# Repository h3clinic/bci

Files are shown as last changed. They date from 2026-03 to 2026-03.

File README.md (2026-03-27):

# BioGENEius Neural Signal Analysis Pipeline

## Model Details

| Field | Value |
|---|---|
| **Name** | BioGENEius Computational Pipeline v1 |
| **Version** | 1.0.0 |
| **Architecture** | Two-stage: Classical (CUSUM/RF) + Deep (NeuralQANet) |
| **Parameters** | 76,045 (Deep model) |
| **Framework** | PyTorch (CPU-only, no GPU required) |
| **License** | Research use only |

## Framing

> Artifact-resilient detection of suppression-like electrophysiological
> perturbation signatures under a low-cost phantom protocol.

**Key constraint:** We never claim neurons until we have biology.

## Intended Use

Detection and classification of electrophysiological perturbation signatures
in multichannel time-series data acquired from a low-cost phantom system.
Designed for competition demonstration and research prototyping.

### Primary Use Cases
- Detecting onset of suppression-like perturbations in phantom recordings
- Classifying perturbation cause (9 synthetic proxy classes)
- Quantifying detection latency and classification confidence
- Generating reproducible evaluation reports

### Out of Scope
- Clinical diagnosis or treatment decisions
- Real-time closed-loop neural interfaces
- Claims about biological neurotoxicity from proxy labels

## Pipeline Architecture

```
Acquire (frames → ADC → µV)
  ↓
QC / Artifact Segmentation (ML mask + quality score)
  ↓
Detect Change (CUSUM or z-score baseline comparison)
  ↓
Classify Cause (RF vs Deep model, 9-class + binary)
  ↓
Report (figures + latency + CI + confidence + "unknown" option)
```

### Stage 1 — Classical Detection
- **CUSUM** change-point detection on channel-averaged RMS
- **Z-score** alternative with sliding baseline window
- Outputs: detected (bool), detection latency (seconds), CUSUM statistic

### Stage 2 — Classical Classification
- **Random Forest** on 20 handcrafted features (RMS ratio, spectral entropy, band powers, etc.)
- Binary (perturbation vs baseline) + 9-class cause classification
- Wilson confidence intervals on all accuracy metrics

### Stage 3 — Deep Classification (NeuralQANet)
- 1D CNN backbone → attention pooling → 3 heads:
  - Artifact mask (binary per-sample)
  - Cause classification (9-class)
  - Severity regression (continuous 0–1)
- Self-supervised pretraining: masked reconstruction + NT-Xent contrastive loss
- 7 domain-randomization augmentations: 60Hz injection, channel dropout, gain jitter, coupling, drift, clipping, time mask
- Temperature-calibrated output probabilities

## Proxy Labels — What We Claim and What We Don't

All perturbation classes are **proxy signatures†**, not validated biological effects:

| Class | Proxy Signature | What It Actually Is |
|---|---|---|
| Spike Suppression† | Reduced spike amplitude/rate | Synthetic amplitude modulation |
| Burst Collapse† | Loss of burst patterns | Synthetic burst removal |
| Spectral Shift† | Changed power spectrum | Synthetic PSD warping |
| Mixed Suppression† | Combined signatures | Multiple synthetic effects |
| Amplitude Modulation† | Gain changes | Synthetic scaling |
| Frequency Drift† | Center frequency shift | Synthetic frequency modulation |
| Baseline Drift† | DC offset wander | Synthetic drift injection |
| Coupling Change† | Inter-channel correlation shift | Synthetic coupling matrix |
| Artifact Injection† | Non-physiological transient | Synthetic artifact waveforms |

**†** = proxy label. Biological validation requires phantom recordings
with known perturbation agents under controlled conditions.

## Training Data

- **Source**: `analysis/perturbation_library.py` — deterministic synthetic generators
- **Classes**: 9 perturbation types + baseline
- **Severities**: 3 levels (0.3, 0.6, 0.9)
- **Channels**: 16 (configurable)
- **Sample rate**: 20 kHz (configurable)
- **Augmentations**: 7 domain-randomization transforms

**No real biological data was used for training or evaluation.**

## Evaluation Protocol

| Figure | What It Tests |
|---|---|
| Fig 1 | Onset detection latency + false positive rate |
| Fig 2 | Cause classification confusion matrix + ROC |
| Fig 3 | Robustness under noise and artifact stress |
| Fig 4 | Ablation — why two-stage matters |
| Fig 5 | 3-way comparison: Classical vs RF vs Deep |
| Fig 6 | Stress grid: SNR × severity (where Deep beats Classical) |
| Fig 7 | Domain shift: train A / test B generalization |

### ML Earns Its Keep
- **Random noise floor**: ML does NOT beat physics. PCB shielding + analog design does.
- **Structured artifacts**: ML DOES help with 60Hz, coupling, drift, and other patterned contamination.
- Deep model must beat RF baseline to be included; RF must beat CUSUM to be included.

## Known Limitations

1. **Synthetic only** — All training/evaluation on synthetic perturbation library. No real data yet.
2. **Domain shift** — Performance may degrade when real phantom data differs from synthetic assumptions.
3. **Small model** — 76K params is deliberately small for CPU inference; may under-fit complex patterns.
4. **Temperature calibration** — Calibrated on synthetic validation set; re-calibrate on real data.
5. **Proxy labels** — No biological ground truth. Labels describe electrical signatures, not mechanisms.
6. **Single phantom protocol** — Validated only against BioGENEius Phantom Protocol v2.

## "Unknown" Behavior

When the model encounters data that doesn't match any trained class:
- Top-class probability drops below 0.3
- System flags as "low-confidence" in predictions.csv
- **Intended behavior: don't make a call when you don't know**

## Reproducibility

```bash
# One command. Generates everything.
python analysis/run_pipeline.py --source synthetic --seed 42

# Outputs to out/run_YYYYMMDD_HHMMSS/:
#   fig1–fig7 (PNG), predictions.csv, metrics.json, model_card.md
```

All random state is seeded. Same seed → same results.

## Ethical Considerations

- This system processes synthetic electrical signals, not human data
- No patient data, no clinical decisions, no diagnostic claims
- Proxy labels are clearly marked to prevent over-interpretation
- "Unknown" class prevents forced classification of novel patterns
- All code and evaluation are fully reproducible and auditable

## Citation

If referencing this work, please cite the BioGENEius competition entry
and note that all results are from synthetic simulation studies.

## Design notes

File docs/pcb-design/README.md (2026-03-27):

# Neural AFE Platform - PCB Design Directions

This directory contains the complete design direction set for a 128-channel neural analog front-end (AFE) platform intended for **in-vitro instrumentation**.

## Document Structure

| Document | Purpose |
|---|---|
| `00-board-architecture.md` | Board type decisions and system partitioning |
| `01-requirements-template.md` | Requirements freeze checklist (fill before design) |
| `02-block-architecture.md` | Schematic block definitions and interfaces |
| `03-schematic-capture.md` | Hierarchical schematic organization and workflow |
| `04-layout-rules.md` | Critical layout constraints for neural-level signals |
| `05-bringup-plan.md` | Systematic board bring-up and validation |
| `06-configuration-worksheet.md` | Your specific parameters (fs, egress, etc.) |

## Design Philosophy

1. **Noise is the enemy** — every decision trades off noise
2. **Testability is non-negotiable** — no injection path = weeks of guessing
3. **Separate analog from digital** — physically, electrically, thermally
4. **Lock requirements before drawing** — designing blind wastes boards

## Quick Start

1. Fill out `06-configuration-worksheet.md` with your specific parameters
2. Review `00-board-architecture.md` to confirm board partitioning
3. Complete `01-requirements-template.md` and freeze it
4. Follow schematic and layout documents in order

## Status

- [ ] Configuration worksheet completed
- [ ] Requirements frozen
- [ ] Schematic capture complete
- [ ] Layout complete
- [ ] Fabrication
- [ ] Bring-up complete

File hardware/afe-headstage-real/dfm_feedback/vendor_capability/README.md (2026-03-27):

# Vendor Capability Evidence

Store evidence that your chosen PCB vendor can perform IPC-4761 Type VII
VIPPO (epoxy plug + copper cap) for:

- Drill: 0.200 mm
- Pad:   0.400 mm
- Board: 4-layer, 1.6 mm, FR4

## Required evidence (at least one):

- Email confirmation from vendor CAM engineer (PDF export)
- Screenshot of vendor capability page showing Type VII
- Order line item or quote showing VIPPO selected
- Vendor datasheet for via fill process

## Naming convention:

    <vendor>_<YYYYMMDD>_vippo_capability.<ext>

Example:
    jlcpcb_20260301_vippo_capability.pdf
    pcbway_20260315_vippo_capability.png

## Required keywords in evidence:

At least one file must contain references to:
- Type VII (or IPC-4761 Type VII)
- Epoxy plug (or via fill)
- Copper cap (or cap plating)
- Via-in-pad

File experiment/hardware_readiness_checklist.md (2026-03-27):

# Hardware Readiness Checklist v1.0

**Board:** AFE Headstage v1 (afe-headstage-v1)  
**Order:** JLCPCB 12006563A-Y3  
**Date:** 2026-03-02  
**Runtime contract:** `experiment/device_runtime_contract_v1.md`  
**Phantom protocol:** `experiment/phantom_protocol_v2.md`

---

## Pre-Requisites

- [ ] Board(s) received and inspected for shipping damage
- [ ] Stencil received (if ordered)
- [ ] All components in BOM available (see `docs/BOM_v1.csv`)
- [ ] Soldering station operational (hot air + iron + microscope)
- [ ] Multimeter, oscilloscope, logic analyzer available

---

## Phase 1 — Bare Board Inspection

*Ref: `hardware/afe-headstage-real/bringup_checklist.txt` Phase 1–3*

| # | Check | Tool | Pass Criterion | Result |
|---|---|---|---|---|
| 1.1 | Board dimensions | Calipers | 30.0 × 24.0 mm ± 0.1 mm | ☐ |
| 1.2 | 4-layer stackup | Edge inspection | 4 copper layers visible | ☐ |
| 1.3 | ENIG finish quality | Microscope 20× | Uniform gold, no nickel bleed | ☐ |
| 1.4 | Soldermask integrity | Microscope 20× | No pinholes, no mask on pads | ☐ |
| 1.5 | Silkscreen legible | Visual | Component refs readable | ☐ |
| 1.6 | Edge cuts clean | Visual | No burrs, no delamination | ☐ |
| 1.7 | J5 VIP pads flat | Microscope 40× | No dimples > 25 µm | ☐ |
| 1.8 | VIP pad count | Count against `vip_vias.csv` | 14 VIP pads present | ☐ |
| 1.9 | No epoxy bleed at VIP | Microscope 40× | Epoxy within pad boundary | ☐ |

**Phase 1 verdict:** ☐ GO / ☐ NO-GO (if any fail → reject board)

---

## Phase 2 — Continuity Checks (Before Assembly)

| # | Check | Probe Points | Pass Criterion | Result |
|---|---|---|---|---|
| 2.1 | GND continuity | Any two GND vias, opposite sides | < 1 Ω | ☐ |
| 2.2 | VDD33 continuity | J1 power pin → nearest bypass cap pad | < 1 Ω | ☐ |
| 2.3 | No electrode shorts | Adjacent electrode pads at J5 | > 10 MΩ each pair | ☐ |
| 2.4 | SPI trace continuity | J1 SCLK pin → U1 SCLK pad (via R-pad) | < 5 Ω | ☐ |
| 2.5 | No power-GND short | VDD33 to GND | > 1 MΩ | ☐ |

**Phase 2 verdict:** ☐ GO / ☐ NO-GO

---

## Phase 3 — Assembly

| # | Step | Method | Verification |
|---|---|---|---|
| 3.1 | Apply solder paste | Stencil (0.12mm) or manual | Inspect paste deposit under microscope |
| 3.2 | Place U1 (RHD2132, QFN-56) | Vacuum pen, microscope | Pad alignment ±0.1mm, EP centered |
| 3.3 | Place bypass caps (C1–C6) | Tweezers | Correct orientation (if polarized) |
| 3.4 | Place ferrite bead (FB1) | Tweezers | — |
| 3.5 | Place series resistors (R1–R4) | Tweezers | — |
| 3.6 | Place connector J1 | — | Pin 1 orientation verified |
| 3.7 | Reflow | Hot air 245°C, 30s | No solder bridges visible |
| 3.8 | Post-reflow inspection | Microscope 40× | All QFN pins wetted, no bridges |
| 3.9 | Touch-up (if needed) | Iron + flux | Document any rework |

**Assembly verdict:** ☐ GO / ☐ NO-GO

---

## Phase 4 — Power-On (Current-Limited)

**⚠ USE CURRENT-LIMITED POWER SUPPLY ⚠**

| # | Check | Procedure | Pass Criterion | Result |
|---|---|---|---|---|
| 4.1 | Set supply limits | 3.3V, **50 mA current limit** | — | ☐ |
| 4.2 | Connect power | J1 pins 7,8 (+3V3), J1 GND pins | Supply shows voltage | ☐ |
| 4.3 | Initial current draw | Read supply ammeter | **10–20 mA** (RHD2132 typical: 13 mA) | ☐ |
| 4.4 | No thermal issues | Touch U1 after 30s | Not hot to touch (< 40°C) | ☐ |
| 4.5 | AVDD rail voltage | Probe U1 VDD1 pin to GND | 3.30V ± 0.1V | ☐ |
| 4.6 | AVDD post-ferrite | Probe FB1 output | 3.25–3.30V (slight drop OK) | ☐ |
| 4.7 | No oscillation | Scope on AVDD, AC-coupled, 100 MHz BW | No ringing > 50 mVpp | ☐ |

**If current > 50 mA:** STOP. Likely short. Power off immediately.
Inspect solder joints under microscope. Do not proceed.

**Phase 4 verdict:** ☐ GO / ☐ NO-GO

---

## Phase 5 — SPI Bring-Up

| # | Check | Procedure | Pass Criterion | Result |
|---|---|---|---|---|
| 5.1 | Connect to Intan board | Omnetics cable J1 → RHD2000 USB | Physical connection secure | ☐ |
| 5.2 | Launch Intan GUI | USB enumeration | Board detected in software | ☐ |
| 5.3 | Chip detection | Intan GUI auto-detect | RHD2132 identified, 32 channels listed | ☐ |
| 5.4 | SCLK signal quality | Scope on U1 SCLK pin | Clean clock, correct frequency | ☐ |
| 5.5 | MISO signal | Scope on U1 MISO pin | Transitions visible during SPI read | ☐ |
| 5.6 | Register read | Intan GUI: read chip ID register | Returns correct device ID | ☐ |
| 5.7 | Impedance measurement | Intan GUI: run impedance test, all 14 CH | All < 100 kΩ (inputs open) | ☐ |

**Phase 5 verdict:** ☐ GO / ☐ NO-GO

---

## Phase 6 — Noise Floor Verification

| # | Check | Procedure | Pass Criterion | Result |
|---|---|---|---|---|
| 6.1 | Short all inputs | Connect all 14 electrode inputs to REF at J5 | — | ☐ |
| 6.2 | Record 60s | Intan GUI: 20 kS/s, 14 channels, save .rhd | File saved, correct size | ☐ |
| 6.3 | RMS noise per channel | `session_analyzer.py` or manual FFT | **All 14 channels ≤ 3.0 µVrms** | ☐ |
| 6.4 | No 60 Hz spike | FFT of any channel | 60 Hz peak < 1.0 µVrms | ☐ |
| 6.5 | Channel-to-channel isolation | Cross-correlation matrix | All off-diagonal < −40 dB | ☐ |
| 6.6 | DC offset stability | 60s mean per channel | Drift < 50 µV over 60s | ☐ |

**If noise > 3.0 µVrms:** Check Faraday cage, cable routing, GND.
Try adding ferrite on USB cable. Repeat measurement.

**Phase 6 verdict:** ☐ GO / ☐ NO-GO

---

## Phase 7 — First Frames (Software Pipeline Acceptance)

| # | Check | Command | Pass Criterion | Result |
|---|---|---|---|---|
| 7.1 | Smoke test | `python capture.py --smoke-test` | 101 valid, 0 CRC fail, 5 drops | ☐ |
| 7.2 | Load .rhd file | `python rhd_loader.py --input noise_test.rhd --output noise_test.npz` | .npz created, correct shape | ☐ |
| 7.3 | Run neural metrics | `python neural_metrics.py --input noise_test.npz` | Metrics computed, no errors | ☐ |
| 7.4 | Run session analyzer | `python session_analyzer.py --input noise_test.npz --onset 30` | Results CSV generated | ☐ |
| 7.5 | Run eval_report (synthetic) | `python eval_report.py --out out/test_panels/` | 4 PNG figures generated | ☐ |

**Phase 7 verdict:** ☐ GO / ☐ NO-GO

---

## Phase 8 — Saline Phantom Dry Run

| # | Check | Procedure | Pass Criterion | Result |
|---|---|---|---|---|
| 8.1 | Electrode array construction | Build 14-wire 2×7 array per protocol | Wires secure, tips stripped 5mm | ☐ |
| 8.2 | Saline preparation | 0.9% NaCl, 200 mL distilled water | Dissolved, labeled | ☐ |
| 8.3 | Submerge electrodes | 10mm depth, reference at far end | All tips submerged | ☐ |
| 8.4 | Noise floor in saline | Record 60s, compute RMS | **All channels ≤ 5.0 µVrms** | ☐ |
| 8.5 | Apply test perturbation | Swap to 0.1% saline (impedance shift) | Detection within 5s by eye on scope | ☐ |
| 8.6 | Run analysis on test trial | Full pipeline: record → .rhd → .npz → session_analyzer | Perturbation detected, latency reported | ☐ |

**Phase 8 verdict:** ☐ GO to full experiment / ☐ Iterate

---

## Sign-Off

| Phase | Verdict | Date | Initials | Notes |
|---|---|---|---|---|
| 1. Bare board | | | | |
| 2. Continuity | | | | |
| 3. Assembly | | | | |
| 4. Power-on | | | | |
| 5. SPI | | | | |
| 6. Noise floor | | | | |
| 7. First frames | | | | |
| 8. Phantom dry run | | | | |

**Overall hardware readiness:** ☐ READY / ☐ NOT READY

---

## Appendix: Failure Escalation Quick Reference

| Symptom | Phase | Action |
|---|---|---|
| VIP pads dimpled | 1 | Request vendor cross-section; reject lot if > 25 µm |
| Short between power and GND | 2 | Do NOT assemble; inspect for fab defect |
| Current > 50 mA at power-on | 4 | Power off immediately; inspect QFN solder bridges |
| Intan GUI doesn't detect chip | 5 | Check SCLK/MOSI with scope; re-solder SPI pins |
| Noise > 5 µVrms | 6 | Improve shielding; check GND continuity; try shorter cables |
| Pipeline errors | 7 | Check Python environment; run `pytest` regression |

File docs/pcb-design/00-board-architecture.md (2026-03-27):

# 00 - Board Architecture Decision

## The Three Board Types (Don't Confuse Them)

| Type | What It Contains | Proximity to Electrodes |
|---|---|---|
| **AFE Headstage** | Analog front-end + ADC | Closest (cm scale) |
| **Digital Carrier** | FPGA/MCU, USB/Ethernet, storage | Further (can be meters) |
| **Breakout/Adapter** | Connectors, protection, routing | At electrode interface |

## 128-Channel Recommendation

For 128 channels, **always separate (1) and (2)** with a controlled interconnect.

```
┌─────────────────┐         ┌──────────────────┐
│  AFE Headstage  │◄───────►│  Digital Carrier │
│  (Analog Core)  │  short  │  (FPGA/MCU/USB)  │
│                 │  cable  │                  │
└────────┬────────┘         └──────────────────┘
         │
         ▼
   ┌───────────┐
   │ Electrodes│
   │ (MEA/etc) │
   └───────────┘
```

### Why Separate?

| Problem | Single-Board | Two-Board |
|---|---|---|
| Digital switching noise coupling into analog | Severe | Controllable |
| Thermal management | Hard (MCU heats AFE) | Isolated |
| Iteration speed | Respin entire system | Update carrier only |
| Form factor at electrodes | Bulky | Compact headstage |
| EMI compliance | Nightmare | Manageable |

## Interconnect Options (Headstage ↔ Carrier)

| Method | Bandwidth | Length | Complexity |
|---|---|---|---|
| Flex cable (LVDS) | High | 5–30 cm | Medium |
| Board-to-board connector | High | <5 cm | Low |
| SPI over shielded cable | Medium | <1 m | Low |
| Serialized LVDS (e.g., TI DS90) | Very high | 1–3 m | High |

### Recommended Starting Point

**Board-to-board connector** (Samtec, Hirose) if headstage sits on carrier.
**Flex cable with LVDS** if headstage needs physical separation (typical for MEA setups).

## Decision Checkpoint

Before proceeding, confirm:

- [ ] I am building a **headstage board** (analog core)
- [ ] I am building a **carrier board** (digital backend)
- [ ] I am building **both** as a system
- [ ] Interconnect method selected: _______________
- [ ] Maximum interconnect length: _______________ cm

## Single-Board Exception

Only consider single-board if:
- Channel count < 32
- Sample rate < 10 kS/s
- You have extensive mixed-signal layout experience
- Physical constraints absolutely require it

Even then, **partition the layout** as if they were separate boards.

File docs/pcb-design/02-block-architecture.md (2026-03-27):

# 02 - Block Architecture

## System Block Diagram

```
                                    ┌─────────────────────────────────────────────────┐
                                    │              AFE HEADSTAGE BOARD                │
┌──────────┐                        │                                                 │
│          │    ┌───────────────────┼──────────────────┐                              │
│Electrodes│───►│ A) ELECTRODE      │                  │                              │
│  (128)   │    │    INPUTS         │                  │                              │
│          │    │  • ESD protection │                  │                              │
└──────────┘    │  • Bias network   │     ┌────────────┴────────────┐                 │
                │  • Input RC       │     │                         │                 │
   ┌────────┐   └───────────────────┼────►│  C) AFE + ADC BLOCK     │                 │
   │Reference│                      │     │   • LNA chain           │                 │
   │Electrode│──────────────────────┼────►│   • Filtering           │                 │
   └────────┘   ┌───────────────────┼─────│   • ADC (often integrated)                │
                │ B) REFERENCE &    │     │   • Anti-alias          │                 │
                │    COMMON-MODE    │     └────────────┬────────────┘                 │
                │  • Ref routing    │                  │                              │
                │  • Ground return  │                  │ Digital data                 │
                └───────────────────┘                  ▼                              │
                                          ┌────────────────────────┐                  │
          ┌──────────────────┐            │ D) CLOCKING/TIMING     │                  │
          │ E) POWER         │            │  • Clean clock source  │                  │
          │  • Analog rails  │───────────►│  • Deterministic frame │                  │
          │  • Digital rails │            │  • Timestamp/sequence  │                  │
          │  • Filtering     │            └────────────┬───────────┘                  │
          │  • Ground plan   │                         │                              │
          └──────────────────┘                         ▼                              │
                                          ┌────────────────────────┐                  │
          ┌──────────────────┐            │ F) DIGITAL EGRESS      │◄─────────────────┤
          │ G) TESTABILITY   │            │  • High-speed link     │    Interconnect  │
          │  • Short inputs  │───────────►│  • Packet framing      │    to Carrier    │
          │  • Cal injection │            │  • Sequence IDs        │                  │
          │  • Test points   │            └────────────────────────┘                  │
          │  • Isolation     │                                                        │
          └──────────────────┘                                                        │
                                    └─────────────────────────────────────────────────┘
```

---

## A) Electrode Inputs (Per Channel)

### Requirements
- Handle DC offsets from electrode-electrolyte interface
- Protect AFE from ESD events
- Define a DC bias path (electrodes must not float)

### Circuit Elements

```
Electrode ──┬── ESD ──┬── [Optional RC] ──► AFE Input
            │         │
            │         └── Bias resistor to VREF (if AC-coupled)
            │
            └── Shield/guard (if used)
```

### Design Rules

| Element | Guideline |
|---|---|
| ESD diodes | Low leakage (<1 nA), low capacitance (<5 pF) |
| Input capacitor | Only if AC-coupling required; specify based on low-frequency cutoff |
| Bias resistor | High value (10–100 MΩ) to minimize noise contribution |
| Input RC | If used, cutoff >> signal bandwidth (anti-alias is elsewhere) |

### ⚠️ Common Mistakes
- Adding random 100 nF caps at inputs (destroys electrode impedance matching)
- Forgetting bias path (inputs saturate from leakage currents)
- Using TVS diodes with high leakage

---

## B) Reference & Common-Mode Strategy

### Options

| Strategy | Pros | Cons |
|---|---|---|
| Dedicated reference electrode | Simple, low noise | Requires extra electrode |
| Average reference (computed) | No extra electrode | Increases digital complexity |
| Driven reference | Cancels common-mode | Stability concerns |

### Ground Return Rules

1. Reference electrode connects to **analog ground** near ADC reference
2. This is the **only** intentional connection between electrode system and board ground
3. Do not connect electrode shield to chassis ground (creates ground loops)

### Schematic Checklist
- [ ] Reference electrode input clearly marked
- [ ] Return path to analog ground defined
- [ ] Reference buffer (if driven reference)
- [ ] Reference selection jumpers (if multiple modes)

---

## C) AFE + ADC Block

### Typical Integrated AFE Options

| Part Family | Channels | Integrated ADC | Notes |
|---|---|---|---|
| Intan RHD2164 | 64 | Yes (16-bit) | Neural-specific, SPI |
| Intan RHD2132 | 32 | Yes (16-bit) | Lower channel count |
| TI ADS1299 | 8 | Yes (24-bit) | EEG-focused, daisy-chain |
| Analog Devices AD7124 | 8 | Yes (24-bit) | Precision, lower channel |

For 128 channels:
- 2× RHD2164, or
- 4× RHD2132, or
- 16× ADS1299 (daisy-chained)

### Anti-Alias Strategy

```
Signal BW: 6 kHz (spikes)
Sample rate: 30 kS/s
Nyquist: 15 kHz

Anti-alias filter cutoff: ≤ 10 kHz (with margin)
Filter order: Depends on ADC's input bandwidth and oversampling
```

Many integrated AFEs have built-in anti-alias—**verify in datasheet**.

### Schematic Checklist
- [ ] AFE IC placed with all required decoupling
- [ ] Reference voltage generation (internal or external)
- [ ] Gain configuration (resistors or register settings)
- [ ] Filter configuration (if programmable)
- [ ] Digital interface signals (SPI/parallel)

---

## D) Clocking/Timing

### Requirements
- Low-jitter clock for ADC
- Deterministic sample timing
- Ability to correlate with external events

### Clock Architecture

```
┌──────────────┐     ┌─────────────┐     ┌─────────┐
│ Crystal/TCXO │────►│ Clock buffer│────►│ AFE/ADC │
│   (master)   │     │  (fan-out)  │     │ (MCLK)  │
└──────────────┘     └──────┬──────┘     └─────────┘
                            │
                            ▼
                     ┌─────────────┐
                     │  MCU/FPGA   │
                     │ (sync clock)│
                     └─────────────┘
```

### Specifications

| Parameter | Target | Notes |
|---|---|---|
| Clock frequency | Per AFE requirements | e.g., 2.048 MHz for Intan |
| Jitter (RMS) | < 10 ps | For neural, less critical than RF |
| Clock type | Crystal oscillator or TCXO | Avoid RC oscillators |

### Timestamping Options
1. **Hardware counter** in FPGA/MCU, latched with each sample
2. **Sequence number** per packet (detect drops, not absolute time)
3. **External sync input** for multi-board or stimulus sync

---

## E) Power Architecture

### Rail Definitions

| Rail | Voltage | Purpose | Current Est. |
|---|---|---|---|
| AVDD | 3.3V or 2.5V | AFE analog supply | ~50 mA |
| AVSS | GND or -2.5V | AFE analog return | — |
| DVDD | 3.3V or 1.8V | AFE digital supply | ~20 mA |
| DVSS | GND | AFE digital return | — |
| VIO | 3.3V or 1.8V | Logic level for interface | ~10 mA |
| VCORE | 1.0–1.2V | MCU/FPGA core (if on board) | ~100 mA |

### Power Tree Example

```
External 5V ─┬─► [LDO 3.3V Analog] ──► AVDD
             │
             ├─► [LDO 3.3V Digital] ──► DVDD
             │
             └─► [Buck 1.2V] ──► VCORE (if FPGA)
```

### Filtering Strategy
- **Pi filter** between analog and digital grounds (if single ground)
- **Ferrite bead** + capacitors at each power domain entry
- **Separate regulators** for analog vs. digital (not just ferrites)

### Ground Strategy

| Approach | When to Use |
|---|---|
| Single ground, partitioned | 4-layer boards, careful layout |
| Split ground, single-point connect | 6-layer, high noise sensitivity |
| Separate ground planes per domain | Complex, rarely needed |

**Rule:** Digital return currents must never flow under analog inputs.

---

## F) Digital Egress

### Bandwidth Requirements

| Channels | Sample Rate | Bits | Raw BW | With Overhead |
|---|---|---|---|---|
| 128 | 20 kS/s | 16 | 5.1 MB/s | 6.2 MB/s |
| 128 | 30 kS/s | 16 | 7.7 MB/s | 9.2 MB/s |
| 128 | 40 kS/s | 16 | 10.2 MB/s | 12.3 MB/s |

### Interface Comparison

| Interface | Practical BW | Latency | Complexity |
|---|---|---|---|
| USB 2.0 HS | ~40 MB/s | Variable | Low |
| USB 3.0 SS | ~400 MB/s | Low | Medium |
| Gigabit Ethernet | ~100 MB/s | Configurable | Medium |
| LVDS to carrier | >100 MB/s | Very low | Low |

### Packet Format Requirements
- **Sequence ID** (32-bit counter minimum)
- **Timestamp** (optional, 32–64 bit)
- **Channel data** (all 128 channels per packet, or chunked)
- **Checksum/CRC** (detect corruption)

### Schematic Checklist
- [ ] Interface PHY/transceiver
- [ ] ESD protection on external lines
- [ ] Proper termination for high-speed signals
- [ ] Connector with defined pinout

---

## G) Testability

### Non-Negotiable Test Features

| Feature | Purpose | Implementation |
|---|---|---|
| Input short | Measure noise floor | CMOS switches or jumpers |
| Cal injection | Verify gain, BW, channel mapping | DAC or resistor divider |
| Rail test points | Debug power issues | Via or pad per rail |
| Isolation jumpers | Separate analog/digital debug | 0Ω resistors |

### Input Shorting Circuit

```
              ┌─── Normal: electrode connected
Electrode ───┤
              └─── Test: all inputs shorted to reference
                   (via CMOS switch, e.g., ADG1414)
```

### Calibration Injection

```
                    ┌──────────────┐
Cal DAC/PWM ───────►│ Attenuator   │───► Injection point
                    │ (1000:1)     │     (before or after input RC)
                    └──────────────┘
```

Injection amplitude: ~100 µVpp to ~1 mVpp (realistic spike amplitude)

### Debug Isolation

```
Analog section ───[0Ω or jumper]─── Digital section

With jumper removed:
- Analog can be powered/tested independently
- Verify analog noise floor without digital switching
```

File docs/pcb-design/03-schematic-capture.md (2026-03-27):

# 03 - Schematic Capture Directions

## Workflow Order (Do This Sequence)

```
1. Power Tree          ──► Define all rails first
2. Connector Strategy  ──► How do 128 channels enter?
3. Reference/CM        ──► Ground and reference plan
4. AFE/ADC            ──► Core acquisition circuit
5. Clocking           ──► Clean clock distribution
6. Digital Interface  ──► Egress path
7. Test/Debug         ──► Injection, isolation, test points
```

**Do not start with the AFE.** Start with power.

---

## Hierarchical Sheet Structure

Create these sheets in your CAD tool (KiCad/Altium/OrCAD):

```
Top Level
├── Power
│   ├── Input Protection
│   ├── Analog Regulators
│   ├── Digital Regulators
│   └── Power Sequencing (if needed)
│
├── Inputs (repeated or arrayed)
│   ├── Channels 1-32
│   ├── Channels 33-64
│   ├── Channels 65-96
│   └── Channels 97-128
│
├── Reference_CM
│   ├── Reference Electrode Interface
│   └── Common-Mode Handling
│
├── AFE_ADC
│   ├── AFE_IC_1 (channels 1-64)
│   └── AFE_IC_2 (channels 65-128)
│
├── Clocking
│   ├── Clock Source
│   └── Distribution
│
├── Digital_Interface
│   ├── MCU/FPGA (if on board)
│   └── Egress (USB/Ethernet/Connector)
│
└── Test_Debug
    ├── Input Shorting
    ├── Cal Injection
    └── Test Points
```

---

## Sheet 1: Power

### 1.1 Define Every Rail

Create a table in your schematic notes:

| Rail Name | Voltage | Tolerance | Max Current | Source | Load |
|---|---|---|---|---|---|
| VIN | 5.0V | ±5% | 500 mA | USB/External | All regulators |
| AVDD | 3.3V | ±2% | 100 mA | LDO_A | AFE analog |
| DVDD_AFE | 3.3V | ±5% | 50 mA | LDO_D | AFE digital |
| VIO | 3.3V | ±5% | 30 mA | LDO_D or separate | Level shifters |
| VCORE | 1.2V | ±3% | 200 mA | Buck | MCU/FPGA core |

### 1.2 Power Tree Diagram

Draw the actual power flow:

```
USB 5V ──┬──[Ferrite]──► VIN_PROT
         │
         └──[TVS]──► GND

VIN_PROT ──┬──► [LDO: ADP151-3.3] ──► AVDD
           │       │
           │       └── Cin: 1µF, Cout: 1µF (per datasheet)
           │
           ├──► [LDO: AP2112K-3.3] ──► DVDD
           │       │
           │       └── Cin: 1µF, Cout: 2.2µF
           │
           └──► [Buck: TPS62840] ──► VCORE (if needed)
```

### 1.3 Ground Hierarchy

Define how grounds connect:

```
USB_GND ──► CHASSIS_GND (optional, via capacitor)
        │
        └──► BOARD_GND ──┬──► AGND (analog section)
                         │
                         └──► DGND (digital section)
                              │
                              └── Connect at single point near power entry
```

### 1.4 Power Schematic Checklist

- [ ] Input protection (TVS, polarity protection if external DC)
- [ ] Input bulk capacitance (10–100 µF depending on source)
- [ ] Each regulator with correct input/output caps
- [ ] Enable pins defined (directly tied or controlled)
- [ ] Power-good indicators (optional but useful)
- [ ] Test points on every rail

---

## Sheet 2: Connectors

### 2.1 Electrode Connector Strategy

For 128 channels, common approaches:

| Connector Type | Channels/Connector | Quantity | Notes |
|---|---|---|---|
| Omnetics NPD-36 | 32 | 4 | Standard neural |
| Samtec QSH/QTH | 50+ | 2-3 | High density |
| Hirose FX23 | 100+ | 1-2 | Very high density |
| Custom flex | 128 | 1 | Requires flex PCB |

### 2.2 Pinout Strategy

**Do not randomly assign pins.** Follow this logic:

```
Connector Pinout (example for 36-pin Omnetics):
- Pins 1-32: Signal channels (sequential)
- Pins 33-34: Reference electrodes
- Pins 35-36: Ground/Shield

Arrange so:
- Adjacent channels are adjacent pins (reduces crosstalk issues)
- Reference pins are at end (easy routing)
- Ground pins at corners (shield routing)
```

### 2.3 Reference/Shield Pinout

| Pin | Function | Connection |
|-----|---|---|
| REF1 | Reference electrode 1 | To reference buffer input |
| REF2 | Reference electrode 2 (optional) | Selectable or differential |
| GND | Electrode ground | AGND (star point) |
| SHIELD | Cable shield (if used) | AGND via 0Ω or capacitor |

### 2.4 Connector Schematic Checklist

- [ ] All 128 channel pins mapped
- [ ] Reference pins clearly labeled
- [ ] Ground/shield pins defined
- [ ] Mechanical footprint verified
- [ ] ESD protection immediately after connector

---

## Sheet 3: Inputs

### 3.1 Per-Channel Circuit

```
            ESD              Input Network           To AFE
Connector ──┬──►[TVS]──┬────[Rbias]────┬──────────► CH_IN
            │          │       │        │
            │          │       ▼        │
            │          │     VBIAS      │
            │          │               [Cin] (if AC-coupled)
            │          │                │
            │          └────────────────┴──► AGND
            │
            └─► Shield (if used)
```

### 3.2 Component Selection

| Component | Value | Rationale |
|---|---|---|
| ESD TVS | PESD5V0S1BL or similar | <1 nA leakage, <5 pF |
| Rbias | 10–100 MΩ | High to minimize noise, but must sink input bias current |
| Cin | 100 nF–1 µF | Only if AC-coupling needed; sets HPF with Rbias |
| VBIAS | Mid-supply or dedicated | Stable, low-noise reference |

### 3.3 Array vs. Individual

For 128 channels, use **schematic repeat** or **hierarchical sheets**:

```
Sheet: Inputs_1_32
  - 32 identical sub-circuits
  - Bus naming: CH[1..32]

Sheet: Inputs_33_64
  - 32 identical sub-circuits
  - Bus naming: CH[33..64]
```

### 3.4 Input Schematic Checklist

- [ ] ESD on every channel
- [ ] Bias path defined for every channel
- [ ] AC-coupling capacitor (if used) with justified value
- [ ] Schematic note: expected electrode impedance range
- [ ] Net names match connector pinout

---

## Sheet 4: Reference and Common-Mode

### 4.1 Reference Electrode Interface

```
REF_ELECTRODE ──► [ESD] ──► [Buffer] ──► REF_SIGNAL (to AFE)
                              │
                              └──► AGND (return)
```

If using driven reference:
```
REF_ELECTRODE ──► [ESD] ──► [Unity-gain buffer] ──► REF_DRIVE
                                    ▲
                                    │
                    Feedback from common-mode signal
```

### 4.2 Schematic Checklist

- [ ] Reference electrode input with ESD
- [ ] Buffer amplifier (if needed)
- [ ] Clear connection to AFE reference input
- [ ] Ground return path explicitly shown

---

## Sheet 5: AFE/ADC

### 5.1 IC Placement

For each AFE IC, include:

```
┌─────────────────────────────────────────┐
│                AFE IC                    │
│                                         │
│  AVDD ──┬── 100nF ──► AGND              │
│         └── 10µF ──► AGND               │
│                                         │
│  DVDD ──┬── 100nF ──► DGND              │
│         └── 10µF ──► DGND               │
│                                         │
│  REFP ──── 10µF ──► AGND                │
│  REFN ──── 10µF ──► AGND (or AVSS)      │
│                                         │
│  MCLK ◄── Clock distribution            │
│  SCLK ──► SPI bus                       │
│  MOSI ◄── SPI bus                       │
│  MISO ──► SPI bus                       │
│  CS ◄── Chip select                     │
│                                         │
│  IN[0..63] ◄── Input channels           │
└─────────────────────────────────────────┘
```

### 5.2 Decoupling Rules

Follow **exactly** what the datasheet says. For Intan RHD series:

| Pin | Capacitor | Notes |
|-----|---|---|
| VDD (each) | 100 nF + 10 µF | Ceramic, close to pin |
| VREF | 10 µF | Low ESR |
| ELEC_TEST | 100 nF | If used |

### 5.3 AFE Schematic Checklist

- [ ] Every power pin decoupled per datasheet
- [ ] Reference voltage generation/connection
- [ ] All input channels connected with correct net names
- [ ] SPI/digital interface signals with correct polarity
- [ ] Chip select directly controlled (no floating)
- [ ] Unused inputs tied appropriately

---

## Sheet 6: Clocking

### 6.1 Clock Source

```
┌────────────────┐        ┌───────────────┐
│ Crystal/TCXO   │───────►│ Clock Buffer  │──┬──► AFE_MCLK
│ (e.g., 2.048MHz)│       │ (e.g., LMK1C1104)│  │
└────────────────┘        └───────────────┘  └──► MCU_CLK
```

### 6.2 Clock Specification

| Parameter | Requirement | Notes |
|---|---|---|
| Frequency | Per AFE datasheet | e.g., 2.048 MHz for Intan |
| Accuracy | ±50 ppm | TCXO if critical |
| Jitter | <50 ps RMS | Typically not critical for neural |
| Output type | LVCMOS/LVDS | Match AFE input |

### 6.3 Clock Schematic Checklist

- [ ] Crystal/oscillator with required load capacitors
- [ ] Buffer with power decoupling
- [ ] Termination at AFE input (if required)
- [ ] Test point for clock verification

---

## Sheet 7: Digital Interface

### 7.1 MCU/FPGA (if on headstage)

Minimal microcontroller for headstage:
- SPI master to AFE
- Clock generation/distribution
- FIFO buffering
- Interface to carrier

### 7.2 Egress Options

**Option A: Direct to carrier (LVDS)**
```
MCU SPI ──► LVDS Driver ──► Flex connector ──► Carrier
```

**Option B: USB on headstage**
```
MCU ──► USB PHY ──► USB connector ──► Host
```

### 7.3 High-Speed Layout Considerations (capture in schematic)

Add schematic notes:
```
NOTE: LVDS pairs require:
- 100Ω differential impedance
- Length matching within 5 mm
- Guard traces or spacing from other signals
```

### 7.4 Digital Interface Schematic Checklist

- [ ] MCU/FPGA with all required support circuits
- [ ] Interface PHY with correct reference resistors
- [ ] ESD protection on external signals
- [ ] Decoupling per IC requirements
- [ ] Connectors with defined pinout
- [ ] Termination resistors placed correctly

---

## Sheet 8: Test and Debug

### 8.1 Input Shorting

```
                    ┌─────────────────────────────────┐
                    │     CMOS Switch Array          │
                    │     (e.g., ADG1414)            │
CH[1..8] from ──────┤IN                          COM├──► VREF
electrodes          │                               │
                    │                           CTRL├◄── TEST_SHORT_EN
                    └─────────────────────────────────┘

TEST_SHORT_EN: GPIO from MCU or jumper
When enabled: all inputs shorted to VREF for noise measurement
```

### 8.2 Calibration Injection

```
                    ┌─────────────────┐
CAL_DAC_OUT ───────►│  R1 (100kΩ)     │
                    ├─────────────────┤
                    │  R2 (100Ω)      ├──► CAL_INJECT
                    └────────┬────────┘
                             │
                           AGND

Attenuation: 1000:1
1V DAC output → 1 mV at injection point

CAL_INJECT routed to selectable input or summed into all channels
```

### 8.3 Power Isolation

```
AVDD_MAIN ──[R_ISO 0Ω]── AVDD_AFE
                │
              [TP]  ← Test point

DVDD_MAIN ──[R_ISO 0Ω]── DVDD_AFE
                │
              [TP]

R_ISO: 0Ω resistor, can be removed for isolation
Alternative: Use load switches for controlled isolation
```

### 8.4 Test Points

Create a test point table:

| TP# | Net | Purpose |
|-----|-----|---|
| TP1 | AVDD | Analog supply |
| TP2 | DVDD | Digital supply |
| TP3 | VREF | Reference voltage |
| TP4 | MCLK | Clock verification |
| TP5 | SPI_MISO | Digital data |
| TP6 | AGND | Ground reference |
| TP7 | CAL_INJECT | Cal signal verify |

### 8.5 Test/Debug Schematic Checklist

- [ ] Input shorting switches with control signal
- [ ] Cal injection circuit with defined attenuation
- [ ] Power isolation resistors
- [ ] Test points for all critical nets
- [ ] JTAG/SWD header for MCU/FPGA
- [ ] Debug LEDs (optional)

---

## Final Schematic Review Checklist

Before proceeding to layout:

### Power
- [ ] All rails defined with source and load
- [ ] Every regulator has correct capacitors
- [ ] Ground connections explicit

### Analog
- [ ] All 128 inputs have ESD and bias
- [ ] Reference electrode path complete
- [ ] AFE decoupled per datasheet

### Digital
- [ ] Clock source and distribution complete
- [ ] SPI/data bus connections verified
- [ ] Egress interface complete

### Test
- [ ] Shorting circuit functional
- [ ] Cal injection path defined
- [ ] Test points placed

### General
- [ ] No unconnected pins (all intentional NC marked)
- [ ] Net names consistent across sheets
- [ ] Schematic notes for layout-critical items
- [ ] BOM review complete

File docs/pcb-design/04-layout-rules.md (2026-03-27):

# 04 - Layout Rules

## The Core Truth

**For neural-level signals, layout is everything.**

You can have a perfect schematic and destroy it with bad layout. These rules are non-negotiable for sub-10 µVrms noise floors.

---

## A) Board Partitioning

### The Two-Island Model

```
┌────────────────────────────────────────────────────────────────┐
│                         PCB OUTLINE                            │
│                                                                │
│  ┌─────────────────────────┐    ┌─────────────────────────┐   │
│  │     ANALOG ISLAND       │    │     DIGITAL ISLAND      │   │
│  │                         │    │                         │   │
│  │  • Electrode inputs     │    │  • MCU/FPGA             │   │
│  │  • AFE ICs              │    │  • USB/Ethernet PHY     │   │
│  │  • Analog regulators    │    │  • Digital regulators   │   │
│  │  • Reference circuits   │    │  • Clocks (if separate) │   │
│  │                         │    │                         │   │
│  └───────────┬─────────────┘    └───────────┬─────────────┘   │
│              │                              │                  │
│              └──────────┬───────────────────┘                  │
│                         │                                      │
│                   ┌─────┴─────┐                                │
│                   │  BRIDGE   │                                │
│                   │ (single   │                                │
│                   │  point)   │                                │
│                   └───────────┘                                │
│                                                                │
└────────────────────────────────────────────────────────────────┘
```

### Bridge Rules

1. **Single connection point** between islands (not scattered vias)
2. Bridge carries:
   - Ground connection
   - Digital data signals (with controlled routing)
   - Power (filtered at bridge)
3. **No high-speed clocks** crossing the bridge on outer layers
4. Bridge width: minimum necessary for signals

### Partitioning Checklist

- [ ] Analog island boundary defined
- [ ] Digital island boundary defined
- [ ] Bridge location identified
- [ ] Component placement respects boundaries
- [ ] No analog traces in digital area and vice versa

---

## B) Return Current Discipline

### The Fundamental Rule

**Current flows in loops. Return current takes the path of least impedance.**

For DC and low frequencies: path of least resistance
For high frequencies: path of least inductance (directly under the trace)

### Ground Plane Requirements

| Layer | Requirement |
|---|---|
| Under analog signals | Solid, unbroken AGND |
| Under digital signals | Solid, unbroken DGND |
| At boundaries | Controlled transition, not random |

### Anti-Patterns (Do NOT Do These)

```
BAD: Split ground with digital trace crossing
┌─────────────────────────────────────────┐
│ AGND plane │ gap │ DGND plane          │
│            │     │                      │
│    ════════╪═════╪════════             │
│    Digital trace crossing gap           │
│    (return current has no path!)        │
└─────────────────────────────────────────┘

BAD: Signal via without nearby ground via
┌─────────┐
│ Signal  │
│ via     │ ← Return current has to find
│  ●      │    distant ground via
│         │
└─────────┘

GOOD: Signal via with adjacent ground via
┌─────────┐
│ ● ●     │ ← Signal and return stay together
│ Sig GND │
└─────────┘
```

### Via Stitching

| Location | Via Spacing |
|---|---|
| Around analog island perimeter | Every 3 mm |
| Adjacent to high-speed signals | Every 2 mm |
| At ground plane transitions | At least 2 vias per transition |

---

## C) Input Signal Routing

### Inputs Are Sacred

The first 10 mm of trace from connector to AFE input is the most critical routing on the board.

### Input Routing Rules

| Rule | Specification |
|---|---|
| Trace length | As short as possible (<10 mm ideal) |
| Trace width | Consistent (e.g., 0.15–0.2 mm) |
| Symmetry | All channels should have similar length/geometry |
| Layer | Keep on one layer if possible |
| Clearance from clocks | >2 mm, perpendicular crossing only |
| Clearance from power | >1 mm |

### Routing Pattern

```
Good: Direct, short, parallel
┌──────────────────────────────────────┐
│ Connector                   AFE      │
│                                      │
│ ●─────────────────────────────●      │
│ ●─────────────────────────────●      │
│ ●─────────────────────────────●      │
│ ●─────────────────────────────●      │
│                                      │
│ (all traces similar length, parallel)│
└──────────────────────────────────────┘

Bad: Long, meandering, crossed
┌──────────────────────────────────────┐
│ Connector                   AFE      │
│                                      │
│ ●────────────────────╮       ╭──●    │
│ ●───╮   ╭────────────┼───────┤       │
│     │   │   ╭────────┴───╮   │       │
│ ●───┴───┴───┤            ├───╯──●    │
│             ╰────────────╯           │
│ (different lengths, crossings = bad) │
└──────────────────────────────────────┘
```

### Guard Traces/Shielding (Advanced)

If you have experience and need it:

```
       GND guard trace
           │
    ●══════╪══════●  Signal trace
           │
       GND guard trace
```

Guard traces should be:
- Connected to AGND with vias every 5 mm
- On the same layer as the signal
- Only used if you understand the tradeoffs

**If unsure: don't guard, just keep inputs short and isolated.**

---

## D) Decoupling Placement

### The 3-3-3 Rule

1. **3 mm maximum** from cap to pin
2. **3 via maximum** in the path (cap → power plane → pin)
3. **3 different values** for broadband filtering (e.g., 10 µF, 100 nF, 10 nF)

### Placement Example

```
┌─────────────────────────────────────────────┐
│                  IC Pin                     │
│                    │                        │
│                    ●  Via to power plane    │
│                    │                        │
│              ┌─────┴─────┐                  │
│              │           │                  │
│           ──┤├──      ──┤├──                │
│           100nF        10µF                 │
│              │           │                  │
│              ●           ●  Vias to GND     │
│                                             │
│   Distance: pin to cap < 3 mm               │
└─────────────────────────────────────────────┘
```

### Decoupling Strategy by IC Type

| IC | High-Freq Cap | Bulk Cap | Notes |
|----|---|---|---|
| AFE (analog supply) | 100 nF ceramic | 10 µF ceramic | Multiple pairs for multi-pin |
| AFE (digital supply) | 100 nF ceramic | 10 µF ceramic | Separate from analog |
| ADC reference | 10 µF + 100 nF | 100 µF | Low ESR critical |
| MCU/FPGA core | 100 nF per pin | 10–47 µF | Follow vendor guidance |
| LDO output | Per datasheet | Per datasheet | Often specifies ESR |

### Via Stitching for Decoupling

```
Cap placement:
         Pin (top)
           │
     ┌─────●─────┐
     │     │     │
    ═╪═   Via   ═╪═   ← Caps on bottom, vias to planes
     │           │
     ●           ●    ← GND vias adjacent to caps
```

---

## E) Layer Stack

### 4-Layer Stack (Minimum for Mixed-Signal)

| Layer | Purpose | Notes |
|---|---|---|
| 1 (Top) | Signals + Components | Analog on analog side, digital on digital side |
| 2 | Ground | Solid, partitioned if needed |
| 3 | Power | Split for AVDD, DVDD |
| 4 (Bottom) | Signals + Components | Same partitioning as top |

**4-layer limitations:**
- Must be very disciplined about partitioning
- Limited routing channels
- Ground continuity harder to maintain

### 6-Layer Stack (Recommended)

| Layer | Purpose | Thickness |
|---|---|---|
| 1 (Top) | Analog signals + AFE components | — |
| 2 | Ground (AGND primary) | Core |
| 3 | Analog power (AVDD) | Prepreg |
| 4 | Digital signals | Core |
| 5 | Ground (DGND primary) | Prepreg |
| 6 (Bottom) | Digital power + signals | — |

**6-layer advantages:**
- Dedicated ground adjacent to each signal layer
- Clear analog/digital separation
- Better EMI performance

### Stack Cross-Section

```
═══════════════════════════════════════════════  L1: Analog signals
━━━━━━━━━━━━━━━━━━━━━━━━━━━━━━━━━━━━━━━━━━━━━━━  L2: Ground (AGND)
┄┄┄┄┄┄┄┄┄┄┄┄┄┄┄┄┄┄┄┄┄┄┄┄┄┄┄┄┄┄┄┄┄┄┄┄┄┄┄┄┄┄┄┄┄┄┄  L3: AVDD
═══════════════════════════════════════════════  L4: Digital signals
━━━━━━━━━━━━━━━━━━━━━━━━━━━━━━━━━━━━━━━━━━━━━━━  L5: Ground (DGND)
═══════════════════════════════════════════════  L6: DVDD + signals
```

### Layer Assignment Rules

| Signal Type | Preferred Layer | Reference Layer |
|---|---|---|
| Electrode inputs | L1 only | L2 (AGND) |
| Analog AFE routing | L1 | L2 (AGND) |
| SPI clock/data | L4 or L6 | L5 (DGND) |
| USB/Ethernet | L6 | L5 (DGND) |
| Power traces | L3 or L6 | — |

---

## F) Specific Layout Guidance

### AFE IC Placement

```
┌──────────────────────────────────────────────────┐
│                                                  │
│    ┌────────────┐                               │
│    │ CONNECTOR  │  ← Electrode input            │
│    └─────┬──────┘                               │
│          │ <10mm                                │
│    ┌─────┴──────┐                               │
│    │    AFE     │  ← Place AFE close to connector│
│    │    IC      │                               │
│    └─────┬──────┘                               │
│          │                                      │
│    ┌─────┴──────┐                               │
│    │  Digital   │  ← Digital further away       │
│    │   Link     │                               │
│    └────────────┘                               │
│                                                  │
└──────────────────────────────────────────────────┘
```

### Clock Routing

| Rule | Specification |
|---|---|
| Trace impedance | 50Ω (single-ended) or per spec |
| Length matching | N/A for low-speed AFE clocks |
| Clearance from analog | Maximum feasible (>2 mm) |
| Layer | Digital layer (L4 or L6) |
| Termination | At destination if >2 inches |

### USB/Ethernet Routing

| Parameter | USB 2.0 HS | Gigabit Ethernet |
|---|---|---|
| Differential impedance | 90Ω ± 10% | 100Ω ± 10% |
| Pair-to-pair spacing | 3× trace width | 3× trace width |
| Length matching (pair) | ±5 mm | ±5 mm |
| Layer | Bottom or L4 | Bottom or L4 |
| Reference plane | Solid, unbroken | Solid, unbroken |

---

## G) DFM and Fabrication Notes

### Minimum Specifications (Standard PCB)

| Parameter | Minimum | Recommended |
|---|---|---|
| Trace width | 0.1 mm | 0.15 mm |
| Trace spacing | 0.1 mm | 0.15 mm |
| Via drill | 0.2 mm | 0.3 mm |
| Via pad | 0.45 mm | 0.5 mm |
| Annular ring | 0.1 mm | 0.125 mm |

### Stack-up Communication

Send this to your fab house:
```
6-Layer Controlled Impedance Stack
----------------------------------
Total thickness target: 1.6 mm ± 10%

L1: Signal (1 oz copper)
   Prepreg: XX µm (calculate for 50Ω microstrip on L1-L2)
L2: Ground (1 oz copper)
   Core: XX µm
L3: Power (0.5 oz copper)
   Prepreg: XX µm
L4: Signal (1 oz copper)
   Core: XX µm
L5: Ground (1 oz copper)
   Prepreg: XX µm (calculate for 50Ω microstrip on L6-L5)
L6: Signal (1 oz copper)

Required impedances:
- 50Ω single-ended microstrip (L1 ref L2, L6 ref L5)
- 90Ω differential (USB, if used)
- 100Ω differential (Ethernet, if used)
```

### Soldermask and Silkscreen

- **Soldermask:** Standard green or matte black (avoid white near analog—reflections can cause visual inspection issues)
- **Silkscreen:** Mark all test points, polarity indicators, pin 1 markers
- **Exposed pad:** Ensure paste aperture for QFN/BGA thermal pads

---

## H) Layout Review Checklist

### Before Sending to Fab

#### Partitioning
- [ ] Analog and digital islands clearly separated
- [ ] Single bridge connection point
- [ ] No digital traces in analog area

#### Ground Planes
- [ ] AGND solid under all analog signals
- [ ] DGND solid under all digital signals
- [ ] Via stitching at island perimeter
- [ ] No unnecessary ground plane cuts

#### Input Routing
- [ ] Electrode inputs <10 mm length
- [ ] All input traces similar length
- [ ] Inputs clear of clocks and digital signals
- [ ] Inputs on single layer with solid reference

#### Decoupling
- [ ] All caps <3 mm from pins
- [ ] Via to plane for each cap
- [ ] GND via adjacent to each cap

#### High-Speed Signals
- [ ] Impedance controlled per design rules
- [ ] Length matching where required
- [ ] Reference plane unbroken under traces
- [ ] Signal/return vias paired

#### Power
- [ ] Each rail clearly routed
- [ ] Adequate copper for current
- [ ] Thermal relief for test points (not for power delivery)

#### Testability
- [ ] Test points accessible
- [ ] Isolation resistors placeable
- [ ] JTAG/SWD header accessible

#### DFM
- [ ] Design rules pass
- [ ] Impedance calculation provided to fab
- [ ] Stack-up clearly specified
- [ ] Gerbers reviewed visually

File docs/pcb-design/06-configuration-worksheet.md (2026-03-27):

# 06 - Configuration Worksheet

## ⚠️ FILL THIS OUT FIRST

This worksheet captures the two critical parameters needed for precise design directions. Complete this before requesting detailed guidance.

---

## Your Configuration

### Sample Rate

```
fs = ________ kS/s per channel
```

Common values:
| Application | Typical fs |
|---|---|
| LFP only (1-300 Hz) | 1-2 kS/s |
| Spikes (300-6000 Hz) | 20-30 kS/s |
| Spikes + headroom | 30-40 kS/s |
| Wideband (LFP + spikes) | 30 kS/s |

### Digital Egress

```
egress = ________________
```

Options:
- [ ] USB 2.0 (easiest, limited to ~40 MB/s practical)
- [ ] USB 3.0 (higher bandwidth, more complex)
- [ ] Gigabit Ethernet (good for distance, moderate complexity)
- [ ] Board-to-board (headstage → separate carrier)

---

## Bandwidth Calculation

Given your fs, calculate required bandwidth:

```
Channels:        128
Sample rate:     ________ kS/s
Bits per sample: 16

Raw data rate = 128 × fs × 16 / 8 = ________ MB/s
With overhead:  ________ MB/s × 1.2 = ________ MB/s
```

### Interface Feasibility Check

| Interface | Max Practical BW | Your Requirement | Feasible? |
|---|---|---|---|
| USB 2.0 HS | ~40 MB/s | ________ MB/s | ☐ Yes ☐ No |
| USB 3.0 SS | ~400 MB/s | ________ MB/s | ☐ Yes ☐ No |
| Gigabit Ethernet | ~100 MB/s | ________ MB/s | ☐ Yes ☐ No |
| Board-to-board LVDS | >100 MB/s | ________ MB/s | ☐ Yes ☐ No |

---

## Example Configurations

### Configuration A: Low-Rate LFP System
```
fs = 2 kS/s per channel
egress = USB 2.0

Calculation:
  128 × 2000 × 16 / 8 = 0.51 MB/s
  With overhead: 0.6 MB/s
  
USB 2.0 feasibility: YES (0.6 << 40 MB/s)

Recommendation:
  - Single-board possible
  - Simple USB 2.0 implementation
  - 4-layer PCB acceptable
```

### Configuration B: Standard Spike Recording
```
fs = 30 kS/s per channel
egress = USB 3.0

Calculation:
  128 × 30000 × 16 / 8 = 7.68 MB/s
  With overhead: 9.2 MB/s
  
USB 3.0 feasibility: YES (9.2 << 400 MB/s)
USB 2.0 feasibility: YES (9.2 < 40 MB/s, but tight)

Recommendation:
  - USB 2.0 possible but margin is low
  - USB 3.0 recommended for headroom
  - 6-layer PCB recommended
```

### Configuration C: High-Rate Research System
```
fs = 40 kS/s per channel
egress = Gigabit Ethernet

Calculation:
  128 × 40000 × 16 / 8 = 10.24 MB/s
  With overhead: 12.3 MB/s
  
Gigabit Ethernet feasibility: YES (12.3 << 100 MB/s)

Recommendation:
  - Ethernet provides distance flexibility
  - May want headstage + carrier split
  - 6-layer PCB required
```

### Configuration D: Headstage + Carrier Architecture
```
fs = 30 kS/s per channel
egress = Board-to-board to carrier

Headstage → LVDS → Carrier → USB 3.0 → Host

Recommendation:
  - Headstage: compact, 4-layer, LVDS out
  - Carrier: 6-layer, FPGA/MCU, USB 3.0
  - Best noise isolation
  - Most flexibility
```

---

## Your Selection

Complete this section:

```
Selected sample rate: fs = ________ kS/s

Selected egress: ________________

Calculated data rate: ________ MB/s

Architecture decision:
  [ ] Single board
  [ ] Headstage + Carrier

Layer count:
  [ ] 4-layer
  [ ] 6-layer
```

---

## Next Steps

Once you complete this worksheet, you will receive:

1. **Concrete schematic sheet checklist** — exact signals/rails to include
2. **Recommended layer stackup** — impedance targets, layer assignment
3. **Connector pinout strategy** — 128-channel routing plan
4. **Customized bring-up checklist** — specific to your architecture

---

## Submit Your Configuration

Provide the following:

```
fs = ____ kS/s per channel
egress = USB / Ethernet / board-to-board to carrier
```

Example response:
```
fs = 30 kS/s per channel
egress = USB 3.0
```

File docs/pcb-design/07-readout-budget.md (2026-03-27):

# 07 — Readout Budget
## Neural AFE Headstage — 128 Channel
### Document Status: VALIDATED against Intan-RHX v3.5.0 source code (GPLv3)

---

## 1. Locked Parameters

| Parameter | Value | Source |
|---|---|---|
| fs | 30 kS/s per channel | RHD2164 max (Intan product page, confirmed in `rhxglobals.h` `SampleRate30000Hz = 16`) |
| Channels | 128 (2× RHD2164) | Architecture spec |
| ADC bits | 16 | Intan product page: "16-bit ADC" |
| Egress | LVDS to digital carrier | Architecture spec |

---

## 2. Raw Throughput

```
128 ch × 30,000 S/s × 16 bit = 61,440,000 bit/s
                               = 61.44 Mbps
                               = 7.68 MB/s
```

---

## 3. LVDS Egress Capacity

| Parameter | Value |
|---|---|
| Driver | DS90LV047A (quad) |
| Data lanes | 2 (LVDS0, LVDS1) |
| Per-lane rate | 100 Mbps (claimed in schematic) |
| Total capacity | 200 Mbps |
| **Margin** | **200 / 61.44 = 3.25×** |

With 20% framing overhead: 61.44 × 1.2 = 73.7 Mbps → still 2.7× margin.

⚠️ **UNVERIFIED**: The 100 Mbps per lane is a design target, not a DS90LV047A spec limit.
DS90LV047A supports up to 400 Mbps per channel. The actual rate depends on the
serialization scheme implemented in the MCU/FPGA firmware. This needs to be defined.

---

## 4. RHD2164 SPI Protocol — FROM SOURCE CODE

### 4.1 Critical Architecture Fact

**The RHD2164 uses DDR SPI (Double Data Rate) with two MISO lines.**

From `rhxglobals.h`:
```cpp
enum BoardDataSource {
    PortA1 = 0, PortA2 = 1,   // Standard SPI streams
    ...
    PortA1Ddr = 8, PortA2Ddr = 9,  // DDR SPI streams
    ...
};

enum ChipType {
    RHD2164Chip = 4,
    RHD2164MISOBChip = 1000    // Second MISO line of RHD2164
};
```

**What DDR means for RHD2164:**
- The chip has **two MISO output lines**: MISO A and MISO B
- Each MISO line outputs **32 channels** of data per SPI command cycle
- Together they provide all 64 channels simultaneously
- This is NOT standard SPI. It requires either:
  - An FPGA with two MISO capture paths, OR
  - An MCU with DDR SPI peripheral support (STM32U5, STM32H7 — per Intan firmware)

### 4.2 Commands Per Sample Period

From `rhxdatablock.h` / `rhxdatablock.cpp`:
```cpp
int RHXDataBlock::channelsPerStream(ControllerType type_) {
    case ControllerRecordUSB2:
    case ControllerRecordUSB3:
        return 32;    // 32 channels per MISO line
}
```

Each SPI command is **16 bits** (MOSI sends command, MISO returns data).

Per sample period (33.33 µs at 30 kS/s), the FPGA sends a sequence of commands:
- **32 CONVERT commands** (one per channel on each MISO line → 64 channels total)
- **3 auxiliary commands** (aux ADC reads, register reads, impedance DAC)
- = **35 commands per sample period** (this is the standard Intan Rhythm protocol)

### 4.3 SPI Clock Requirement

```
35 commands × 16 bits/command = 560 SCLK cycles per sample period
Sample period at 30 kS/s = 33.33 µs
Minimum SCLK = 560 / 33.33 µs = 16.8 MHz
```

**At 20 MHz SCLK:**
- Time per command: 16 bits / 20 MHz = 0.8 µs
- Time for 35 commands: 35 × 0.8 µs = 28.0 µs
- Sample period: 33.33 µs
- **Margin: 33.33 - 28.0 = 5.33 µs (16% idle time)** ✅

### 4.4 Two Chips (128 Channels) — The Real Problem

For 2× RHD2164, each chip needs its own SPI bus (separate CS, shared SCLK ok).

**Option A: Two independent SPI buses (parallel)**
- Each bus runs 35 commands at 20 MHz = 28.0 µs
- Both run simultaneously → fits in 33.33 µs ✅
- Requires: 2 SPI peripherals + 4 MISO capture paths (2 per chip for DDR)
- This is what the FPGA does in Intan's reference design

**Option B: Single SPI bus, multiplexed CS (serial)**
- Total: 2 × 35 = 70 commands at 20 MHz = 56.0 µs
- Sample period: 33.33 µs
- **DOES NOT FIT. 56 > 33.33.** ❌
- Would require reducing to ≤15 kS/s, or increasing SCLK to >34 MHz

---

## 5. MCU vs FPGA — Validated Assessment

### 5.1 Intan's Official MCU Firmware (v1.2, June 2025)

From the release notes:
```
- U5 rhd2164_acquisition: DDR SPI to control RHD2164 with STM32U5
- H7 rhd2164_acquisition: DDR SPI to control RHD2164 with STM32H7
```

**Intan provides working STM32 firmware for RHD2164.** This confirms an MCU *can* do it.

However, the release notes do NOT state:
- Maximum sample rate achieved per channel
- Whether 2× RHD2164 is supported simultaneously
- Whether streaming is sustained or offline (batch) mode

The firmware has a `OFFLINE_TRANSFER` toggle, suggesting real-time streaming
to USB may be limited by MCU throughput.

### 5.2 Our Design Uses STM32G431

| Spec | STM32G431 | STM32U5A5 (Intan) | STM32H723 (Intan) |
|---|---|---|---|
| Core | Cortex-M4 @ 170 MHz | Cortex-M33 @ 160 MHz | Cortex-M7 @ 550 MHz |
| SPI peripherals | 3 | 3 | 6 |
| SPI max clock | 42.5 MHz | 40 MHz | 137.5 MHz |
| DMA channels | 12 | 16 | 16 |
| RAM | 32 KB | 2.5 MB | 1 MB |
| DDR SPI | **NO native DDR SPI** | **YES (OCTOSPI in DDR mode)** | **YES (OCTOSPI)** |

### 🔴 CRITICAL FINDING

**The STM32G431 does NOT have DDR SPI capability.**

The RHD2164 requires DDR SPI (dual MISO). The STM32U5 and STM32H7 have OCTOSPI
peripherals that support DDR mode — this is specifically why Intan chose them.

The STM32G431's SPI peripheral is standard single-data-rate with one MISO line.
It **cannot natively capture both MISO A and MISO B simultaneously**.

**Workarounds:**
1. Bit-bang the second MISO with GPIO + DMA timer capture (fragile, unreliable at 20 MHz)
2. Use both SPI peripherals to each capture one MISO line (requires external clock gating logic)
3. **Replace STM32G431 with STM32U5 or STM32H7** (Intan's proven path)
4. **Use an FPGA** (Intan's primary reference design uses Xilinx Artix-7 on Opal Kelly)

---

## 6. Revised Architecture Recommendation

### Option 1: MCU-based (change MCU)
Replace STM32G431CBU6 with **STM32U5A5ZJT6Q** (NUCLEO board available).
- Use OCTOSPI in DDR mode for each RHD2164
- STM32U5 has 2× OCTOSPI peripherals → can drive 2 chips in parallel
- Intan provides working firmware framework
- **Pro**: Proven path, low risk
- **Con**: Larger package (LQFP144 vs UFQFPN-48), higher power

### Option 2: FPGA on carrier (current architecture, but move SPI control to carrier)
Keep headstage as passive analog frontend. Move ALL digital logic to carrier board:
- Headstage: RHD2164 × 2, connectors, power, clock — no MCU
- Carrier: FPGA drives SPI directly over board-to-board connector
- SPI signals (SCLK, MOSI, MISO_A, MISO_B, CS) run over the B2B connector
- **Pro**: Simplest headstage, proven FPGA reference design
- **Con**: More wires over B2B connector, SPI signal integrity at 20 MHz over flex

### Option 3: Small FPGA on headstage
Replace STM32G431 with Lattice iCE40UP5K or similar:
- Handles DDR SPI natively
- Serializes into LVDS
- ~$2 BOM cost for iCE40
- **Pro**: Correct tool for the job
- **Con**: FPGA development learning curve, need toolchain

---

## 7. What Must Be Validated Before Routing

| # | Test | Pass Criteria | Dev Board |
|---|---|---|---|
| 1 | DDR SPI read from one RHD2164 | 32 channels × 30 kS/s, zero dropped samples, 10 min sustained | NUCLEO-U5A5 or Opal Kelly XEM7310 |
| 2 | DDR SPI read from two RHD2164 | 64+64 = 128 ch × 30 kS/s, zero drops, 10 min | Same |
| 3 | LVDS serialization at target rate | Sustained stream, zero framing errors, monotonic sequence counter | Same + LVDS eval board |
| 4 | End-to-end throughput | 7.68 MB/s to host, <70% MCU/FPGA utilization | Full signal chain |

**None of these tests require the custom PCB.**

---

## 8. Decision Required

The STM32G431 in the current schematic **cannot drive the RHD2164** without
external logic to handle DDR SPI.

Choose one:
- [ ] A. Swap MCU to STM32U5A5 (OCTOSPI DDR, Intan firmware available)
- [ ] B. Swap MCU to STM32H723 (OCTOSPI DDR, Intan firmware available)  
- [ ] C. Replace MCU with small FPGA (iCE40UP5K + LVDS serializer)
- [ ] D. Move all digital to carrier FPGA, keep headstage analog-only
- [ ] E. Other: ___

**Do not route until this decision is made and validated on a dev board.**

---

*Document created: 2026-02-17*
*Source validation: Intan-RHX v3.5.0 (GitHub, GPLv3), Intan STM32 Framework v1.2 release notes*

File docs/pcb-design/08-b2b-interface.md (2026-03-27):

# 08 — Board-to-Board Interface Specification
## Headstage ↔ Carrier Interface — FROZEN
### Document Status: INTERFACE FREEZE — Do not modify without formal review

---

## 1. Interface Summary

| Parameter | Value |
|---|---|
| Connector (headstage) | Samtec QSH-030-01-L-D-A |
| Connector (carrier) | Samtec QTH-030-01-L-D-A |
| Pin count | 30 (dual row, 15 per row) |
| Pitch | 0.5 mm |
| Mating height | 5 mm |
| Signal voltage | 3.3V LVCMOS |
| Power voltage | 3.3–5V (TBD — depends on carrier regulator) |
| Protocol | DDR SPI (Intan RHD2164 native) |

---

## 2. Signal List

| # | Signal | Direction | Voltage | Speed | Description |
|---|---|---|---|---|---|
| 1 | SCLK | Carrier → Headstage | 3.3V LVCMOS | 20 MHz | SPI clock (FPGA-generated) |
| 2 | MOSI | Carrier → Headstage | 3.3V LVCMOS | 20 Mbps | SPI master-out / slave-in |
| 3 | CS1 | Carrier → Headstage | 3.3V LVCMOS | <1 MHz | Chip select for U1 (active low) |
| 4 | CS2 | Carrier → Headstage | 3.3V LVCMOS | <1 MHz | Chip select for U2 (active low) |
| 5 | MISO1_A | Headstage → Carrier | 3.3V LVCMOS | 20 Mbps | U1 DDR MISO A (ch 0–31) |
| 6 | MISO1_B | Headstage → Carrier | 3.3V LVCMOS | 20 Mbps | U1 DDR MISO B (ch 32–63) |
| 7 | MISO2_A | Headstage → Carrier | 3.3V LVCMOS | 20 Mbps | U2 DDR MISO A (ch 0–31) |
| 8 | MISO2_B | Headstage → Carrier | 3.3V LVCMOS | 20 Mbps | U2 DDR MISO B (ch 32–63) |
| 9 | TEST_SHORT_EN | Carrier → Headstage | 3.3V LVCMOS | DC/slow | Input shorting control |
| 10 | CAL_EN | Carrier → Headstage | 3.3V LVCMOS | DC/slow | Cal injection enable |
| 11 | SPARE | — | — | — | Reserved for future use |
| 12 | VIN | Carrier → Headstage | 3.3–5V | DC | Power supply (4 pins) |
| 13 | GND | Common | 0V | — | Ground reference (15 pins) |

---

## 3. Connector Pin Map

```
         Headstage side (component view, looking down at board)

  Row A (odd)              Row B (even)
  ──────────               ──────────
   1: GND                   2: GND              ← Ground fence
   3: SCLK ────────►        4: GND              ← Clock (carrier→HS)
   5: MOSI ────────►        6: GND              ← Data  (carrier→HS)
   7: CS1  ────────►        8: CS2  ────────►   ← Chip selects
   9: GND                  10: GND              ← Ground fence
  11: MISO1_A ◄────        12: MISO1_B ◄────   ← U1 DDR pair (HS→carrier)
  13: GND                  14: GND              ← Ground fence
  15: MISO2_A ◄────        16: MISO2_B ◄────   ← U2 DDR pair (HS→carrier)
  17: GND                  18: GND              ← Ground fence
  19: VIN ═══════►         20: VIN ═══════►     ← Power
  21: GND                  22: GND              ← Power return
  23: VIN ═══════►         24: VIN ═══════►     ← Power
  25: GND                  26: GND              ← Power return
  27: TEST_SHORT_EN ►      28: CAL_EN ────►     ← Test control
  29: SPARE                30: GND              ← Spare + ground
```

---

## 4. Pin Allocation Statistics

| Category | Count | Percentage |
|---|---|---|
| Ground (GND) | 15 | 50% |
| High-speed digital (SPI) | 8 | 27% |
| Power (VIN) | 4 | 13% |
| Control (slow) | 2 | 7% |
| Spare | 1 | 3% |
| **Total** | **30** | **100%** |

Ground ratio: 50% — exceeds the 33% minimum for GSG discipline.

---

## 5. Electrical Specifications

### 5.1 Digital Signal Levels — FROM DATASHEET

**Source:** Intan RHD2000 Series Datasheet, Pages 6, 12, 27

**Supply voltage (VDD):**

| Parameter | Min | Typ | Max | Unit | Source |
|---|---|---|---|---|---|
| VDD (supply) | 3.2 | 3.3 | 3.6 | V | Datasheet p6: "3.2–3.6 V" |
| VDD (derated) | 2.9 | 3.0 | 3.1 | V | Datasheet p27: derated operation table |

**CMOS digital logic levels (LVDS_en = 0):**

| Parameter | Symbol | Min | Max | Unit | Source (verbatim) |
|---|---|---|---|---|---|
| Digital input LOW | VinLO | −0.4 | +0.7 | V | Datasheet p6: "−0.4 – +0.7 V" |
| Digital input HIGH | VinHI | +2.4 | +3.6 | V | Datasheet p6: "2.4 – 3.6 V" |
| Digital output LOW | VOL | — | GND | V | Datasheet p12: "driven to ground" |
| Digital output HIGH | VOH | VDD | — | V | Datasheet p12: "driven to VDD" |
| auxout drive current | IOH/IOL | — | ±2 | mA | Datasheet p32 |

**Critical warnings from datasheet (verbatim, p12):**
> "The digital input pins on the RHD2000 interpret any voltage below 0.7V as
> logic 'low' and any voltage above 2.4V as logic 'high', so the chip can be
> interfaced with standard 2.5V, 3.0V, or 3.3V signals. Digital inputs to the
> RHD2000 should not go below −0.4V, and should never exceed 3.6V. Digital
> outputs from the RHD2000 chip are driven to ground for logic 'low' and to
> VDD for logic 'high'."

> "5V signals should never be applied directly to the chips." (p6)

**FPGA I/O bank constraint:**
The FPGA I/O bank driving the RHD2164 must use **3.3V LVCMOS** (VCCO = 3.3V).
2.5V LVCMOS is also compatible (VIH 2.4V ≥ threshold). 1.8V LVCMOS is **NOT**
compatible (VOH ~1.7V < VIH threshold 2.4V). 5V tolerant I/O must **NOT** be
used without level shifter.

### 5.2 Power

| Parameter | Min | Typ | Max | Unit |
|---|---|---|---|---|
| VIN voltage | 3.3 | 5.0 | 5.5 | V |
| VIN current (headstage) | — | 90 | 160 | mA |
| Pin current rating (QSH) | — | — | 500 | mA/pin |
| VIN pins (4 paralleled) | — | — | 2000 | mA total |

### 5.3 Timing — FROM DATASHEET

**Source:** Intan RHD2164 Datasheet, Page 11 — "SPI Bus Timing Specifications"
(TA = 25°C, VDD = 3.3V)

| Symbol | Parameter | Min | Max | Unit | Source |
|---|---|---|---|---|---|
| tSCLK | SCLK Period | 41.6 | — | ns | Max SCLK freq = 24 MHz |
| tSCLKH | SCLK Pulse Width High | 20.8 | — | ns | |
| tSCLKL | SCLK Pulse Width Low | 20.8 | — | ns | |
| tCS1 | CS Low to SCLK High Setup | 20.8 | — | ns | |
| tCS2 | SCLK Low to CS High Setup | 20.8 | — | ns | |
| tCSOFF | CS High Duration | 154 | — | ns | Between commands |
| tMOSI | MOSI Valid to SCLK↑ Setup | 10.4 | — | ns | |
| tMISO | SCLK/CS↓ to MISO Valid | — | 12 | ns | Propagation delay |
| tCYCLE | Min Cycle Time (between samples) | 950 | — | ns | Max 1.05 MS/s per 32-ch module |

**Design operating point:** SCLK = 20 MHz (50 ns period) — well within 24 MHz max.
Round-trip propagation through B2B connector + traces: estimated <5 ns.
Total timing margin at 20 MHz: 50 ns period − 12 ns MISO delay − 5 ns B2B = 33 ns.

✅ Timing specs now sourced from actual datasheet (no longer estimates).

---

## 6. Signal Integrity Rules

### 6.1 Headstage PCB Rules

| Rule | Specification |
|---|---|
| SPI trace impedance | 50Ω ±10% (microstrip on L4 over L5 GND) |
| SPI trace width | 0.15 mm (6-layer stackup) |
| SCLK length match (U1 vs U2) | ±2 mm |
| MISO trace length (each) | <20 mm (U1/U2 to B2B pad) |
| Separation: SPI vs electrode | ≥3 mm |
| Separation: SPI vs analog signal | ≥2 mm |
| Layer: SPI routing | L4 (digital signals) only |
| Layer: SPI reference | L5 (solid DGND) |
| Via count in SPI path | 0 (no layer transitions) |
| Guard vias along SPI | Optional, 0.8 mm spacing |

### 6.2 Series Damping Resistors

| Location | Signal | Resistor | Value | Default |
|---|---|---|---|---|
| Headstage (at U1 MISO_A pin) | MISO1_A | R_D5 | 33Ω | DNI |
| Headstage (at U1 MISO_B pin) | MISO1_B | R_D6 | 33Ω | DNI |
| Headstage (at U2 MISO_A pin) | MISO2_A | R_D7 | 33Ω | DNI |
| Headstage (at U2 MISO_B pin) | MISO2_B | R_D8 | 33Ω | DNI |
| Headstage (at B2B SCLK pad) | SCLK | R_SCLK | 33Ω | DNI |
| **Carrier** (at FPGA SCLK out) | SCLK | R_D1 | 33Ω | Populate |
| **Carrier** (at FPGA MOSI out) | MOSI | R_D2 | 33Ω | Populate |
| **Carrier** (at FPGA CS1 out) | CS1 | R_D3 | 33Ω | DNI |
| **Carrier** (at FPGA CS2 out) | CS2 | R_D4 | 33Ω | DNI |

All resistors are 0402 footprint. DNI = Do Not Install (populate only if
ringing/overshoot is observed during bring-up).

### 6.3 B2B Connector Layout Rules

- Place B2B connector on edge of headstage PCB (shortest path to carrier)
- Ground pads connected to unbroken L2 (AGND) and L5 (DGND) planes
- No routing under B2B connector footprint on L1 (analog signals)
- VIN pins: wide trace (≥0.5 mm) to bulk decoupling cap, then to LDO
- Power entry point: star ground connection between AGND and DGND

---

## 7. DDR SPI Protocol Notes

### 7.1 What "DDR" Means for RHD2164

The RHD2164 is **not** a standard SPI device. It has two MISO output lines:

- **MISO_A**: Outputs data for amplifier channels 0–31
- **MISO_B**: Outputs data for amplifier channels 32–63

Both lines are active **simultaneously** during each SPI command. The data
is clocked out on the **falling edge** of SCLK (standard SPI CPOL=0, CPHA=0
with data valid after falling edge).

This is called "DDR" in Intan's terminology because two data streams are
output per clock cycle (one on each MISO line), effectively doubling the
data throughput compared to a single-MISO SPI device.

### 7.2 Implications for Carrier FPGA

The carrier FPGA must:
1. Generate SCLK, MOSI, CS1, CS2
2. Capture MISO_A and MISO_B simultaneously for each chip
3. That means **4 MISO capture paths** total (2 per chip)
4. Standard SPI peripherals on MCUs typically have only 1 MISO input
5. FPGA fabric can implement arbitrary numbers of capture paths

### 7.3 Bus Timing per Sample

At 30 kS/s (33.33 µs sample period):
- 35 SPI commands per sample (32 CONVERT + 3 AUX)
- 16 SCLK cycles per command
- 560 SCLK cycles per sample
- At 20 MHz SCLK: 28.0 µs active, 5.33 µs idle (16% margin)

With parallel CS (both chips active on separate CS lines):
- Both chips read simultaneously in 28.0 µs ✅
- Total data per sample: 2 × 2 × 32 × 16 = 2048 bits = 256 bytes

---

## 8. Interface Freeze Checklist

- [x] Connector part number defined (QSH-030 / QTH-030)
- [x] Pin map assigned and documented
- [x] Signal directions documented
- [x] Voltage levels specified (3.3V LVCMOS) — **verified from RHD2000 Series Datasheet p6/p12/p27**
- [x] Timing constraints listed — **verified from RHD2164 Datasheet p11**
- [x] VIH/VIL thresholds documented (VIL <0.7V, VIH >2.4V, absolute max 3.6V)
- [x] Ground allocation ≥33% (actual: 50%)
- [x] Power pins allocated with margin (4 pins, 2A capacity vs 160 mA need)
- [x] Spare pin reserved (1)
- [x] Series damping resistor plan documented
- [x] SI routing rules documented
- [ ] Carrier-side connector footprint verified (TODO: when carrier board starts)
- [x] Actual RHD2164 timing verified from datasheet ✅
- [ ] B2B connector mechanical fit verified with 3D model (TODO)

---

## 9. Change Control

| Date | Rev | Change | Author |
|---|---|---|---|
| 2026-02-17 | 2.0 | Complete redesign: LVDS removed, raw DDR SPI passthrough. MCU removed from headstage. New GSG pinout with 50% ground allocation. | BCIInterface |

**This interface is FROZEN.** Any changes require:
1. Documented justification
2. Impact analysis on both headstage and carrier
3. Version increment in this document

---

*Document created: 2026-02-17*
*Sources: Intan RHD2000 Series Datasheet (v2017-12), Intan RHD2164 Datasheet (v2017-12),
Intan-RHX v3.5.0 source code, Intan LVDS adapter board datasheet, Samtec QSH-030 product page*

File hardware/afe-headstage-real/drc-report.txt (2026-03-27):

** Drc report for afe-headstage-real.kicad_pcb **
** Created on 2026-02-17T22:59:33-0500 **

** Found 14 DRC violations **
[lib_footprint_issues]: The current configuration does not include the footprint library 'Package_BGA'.
    Local override; warning
    @(118.0000 mm, 92.0000 mm): Footprint U1
[lib_footprint_issues]: The current configuration does not include the footprint library 'Package_TO_SOT_SMD'.
    Local override; warning
    @(106.0000 mm, 86.0000 mm): Footprint U2
[lib_footprint_issues]: The current configuration does not include the footprint library 'Connector_Samtec'.
    Local override; warning
    @(118.0000 mm, 114.0000 mm): Footprint J5
[lib_footprint_issues]: The current configuration does not include the footprint library 'Resistor_SMD'.
    Local override; warning
    @(103.0000 mm, 86.0000 mm): Footprint C1
[lib_footprint_issues]: The current configuration does not include the footprint library 'Resistor_SMD'.
    Local override; warning
    @(110.0000 mm, 86.0000 mm): Footprint C2
[lib_footprint_issues]: The current configuration does not include the footprint library 'Resistor_SMD'.
    Local override; warning
    @(128.0000 mm, 86.0000 mm): Footprint C3
[lib_footprint_issues]: The current configuration does not include the footprint library 'Resistor_SMD'.
    Local override; warning
    @(130.0000 mm, 92.0000 mm): Footprint C4
[lib_footprint_issues]: The current configuration does not include the footprint library 'Resistor_SMD'.
    Local override; warning
    @(114.0000 mm, 86.0000 mm): Footprint C5
[lib_footprint_issues]: The current configuration does not include the footprint library 'Resistor_SMD'.
    Local override; warning
    @(122.0000 mm, 86.0000 mm): Footprint FB1
[lib_footprint_issues]: The current configuration does not include the footprint library 'Resistor_SMD'.
    Local override; warning
    @(106.0000 mm, 94.0000 mm): Footprint R1
[lib_footprint_issues]: The current configuration does not include the footprint library 'Resistor_SMD'.
    Local override; warning
    @(106.0000 mm, 97.0000 mm): Footprint R2
[lib_footprint_issues]: The current configuration does not include the footprint library 'Resistor_SMD'.
    Local override; warning
    @(106.0000 mm, 100.0000 mm): Footprint R3
[lib_footprint_issues]: The current configuration does not include the footprint library 'Resistor_SMD'.
    Local override; warning
    @(106.0000 mm, 103.0000 mm): Footprint R4
[lib_footprint_issues]: The current configuration does not include the footprint library 'Resistor_SMD'.
    Local override; warning
    @(130.0000 mm, 98.0000 mm): Footprint R5

** Found 54 unconnected pads **
[unconnected_items]: Missing connection between items
    Local override; error
    @(105.0500 mm, 85.0500 mm): Pad 5 [+3V3] of U2 on F.Cu
    @(109.5200 mm, 86.0000 mm): Pad 1 [+3V3] of C2 on F.Cu
[unconnected_items]: Missing connection between items
    Local override; error
    @(109.5200 mm, 86.0000 mm): Pad 1 [+3V3] of C2 on F.Cu
    @(113.5200 mm, 86.0000 mm): Pad 1 [+3V3] of C5 on F.Cu
[unconnected_items]: Missing connection between items
    Local override; error
    @(114.5000 mm, 95.0000 mm): Pad N2 [+3V3] of U1 on F.Cu
    @(121.0000 mm, 95.0000 mm): Pad N15 [+3V3] of U1 on F.Cu
[unconnected_items]: Missing connection between items
    Local override; error
    @(121.0000 mm, 94.5000 mm): Pad M15 [+3V3] of U1 on F.Cu
    @(121.0000 mm, 95.0000 mm): Pad N15 [+3V3] of U1 on F.Cu
[unconnected_items]: Missing connection between items
    Local override; error
    @(122.4800 mm, 86.0000 mm): Pad 2 [+3V3] of FB1 on F.Cu
    @(121.0000 mm, 94.5000 mm): Pad M15 [+3V3] of U1 on F.Cu
[unconnected_items]: Missing connection between items
    Local override; error
    @(122.4800 mm, 86.0000 mm): Pad 2 [+3V3] of FB1 on F.Cu
    @(113.5200 mm, 86.0000 mm): Pad 1 [+3V3] of C5 on F.Cu
[unconnected_items]: Missing connection between items
    Local override; error
    @(105.5200 mm, 94.0000 mm): Pad 1 [/CH0] of R1 on F.Cu
    @(114.0000 mm, 89.0000 mm): Pad A1 [/CH0] of U1 on F.Cu
[unconnected_items]: Missing connection between items
    Local override; error
    @(105.5200 mm, 97.0000 mm): Pad 1 [/CH1] of R2 on F.Cu
    @(114.5000 mm, 89.0000 mm): Pad A2 [/CH1] of U1 on F.Cu
[unconnected_items]: Missing connection between items
    Local override; error
    @(105.5200 mm, 100.0000 mm): Pad 1 [/CH2] of R3 on F.Cu
    @(115.0000 mm, 89.0000 mm): Pad A3 [/CH2] of U1 on F.Cu
[unconnected_items]: Missing connection between items
    Local override; error
    @(105.5200 mm, 103.0000 mm): Pad 1 [/CH3] of R4 on F.Cu
    @(115.5000 mm, 89.0000 mm): Pad A4 [/CH3] of U1 on F.Cu
[unconnected_items]: Missing connection between items
    Local override; error
    @(121.5200 mm, 86.0000 mm): Pad 1 [/DVDD_AFE] of FB1 on F.Cu
    @(127.5200 mm, 86.0000 mm): Pad 1 [/DVDD_AFE] of C3 on F.Cu
[unconnected_items]: Missing connection between items
    Local override; error
    @(116.0000 mm, 113.2500 mm): Pad 7 [CS1] of J5 on F.Cu
    @(117.5000 mm, 95.0000 mm): Pad N8 [CS1] of U1 on F.Cu
[unconnected_items]: Missing connection between items
    Local override; error
    @(106.0000 mm, 86.9500 mm): Pad 2 [GND] of U2 on F.Cu
    @(103.4800 mm, 86.0000 mm): Pad 2 [GND] of C1 on F.Cu
[unconnected_items]: Missing connection between items
    Local override; error
    @(106.0000 mm, 86.9500 mm): Pad 2 [GND] of U2 on F.Cu
    @(106.4800 mm, 94.0000 mm): Pad 2 [GND] of R1 on F.Cu
[unconnected_items]: Missing connection between items
    Local override; error
    @(106.4800 mm, 97.0000 mm): Pad 2 [GND] of R2 on F.Cu
    @(106.4800 mm, 94.0000 mm): Pad 2 [GND] of R1 on F.Cu
[unconnected_items]: Missing connection between items
    Local override; error
    @(106.4800 mm, 100.0000 mm): Pad 2 [GND] of R3 on F.Cu
    @(106.4800 mm, 97.0000 mm): Pad 2 [GND] of R2 on F.Cu
[unconnected_items]: Missing connection between items
    Local override; error
    @(106.4800 mm, 103.0000 mm): Pad 2 [GND] of R4 on F.Cu
    @(106.4800 mm, 100.0000 mm): Pad 2 [GND] of R3 on F.Cu
[unconnected_items]: Missing connection between items
    Local override; error
    @(110.4800 mm, 86.0000 mm): Pad 2 [GND] of C2 on F.Cu
    @(106.0000 mm, 86.9500 mm): Pad 2 [GND] of U2 on F.Cu
[unconnected_items]: Missing connection between items
    Local override; error
    @(114.0000 mm, 94.0000 mm): Pad L1 [GND] of U1 on F.Cu
    @(114.0000 mm, 95.0000 mm): Pad N1 [GND] of U1 on F.Cu
[unconnected_items]: Missing connection between items
    Local override; error
    @(114.0000 mm, 94.0000 mm): Pad L1 [GND] of U1 on F.Cu
    @(106.4800 mm, 94.0000 mm): Pad 2 [GND] of R1 on F.Cu
[unconnected_items]: Missing connection between items
    Local override; error
    @(114.4800 mm, 86.0000 mm): Pad 2 [GND] of C5 on F.Cu
    @(110.4800 mm, 86.0000 mm): Pad 2 [GND] of C2 on F.Cu
[unconnected_items]: Missing connection between items
    Local override; error
    @(114.5000 mm, 113.2500 mm): Pad 1 [GND] of J5 on F.Cu
    @(106.4800 mm, 103.0000 mm): Pad 2 [GND] of R4 on F.Cu
[unconnected_items]: Missing connection between items
    Local override; error
    @(114.5000 mm, 114.7500 mm): Pad 2 [GND] of J5 on F.Cu
    @(115.0000 mm, 114.7500 mm): Pad 4 [GND] of J5 on F.Cu
[unconnected_items]: Missing connection between items
    Local override; error
    @(114.5000 mm, 114.7500 mm): Pad 2 [GND] of J5 on F.Cu
    @(114.5000 mm, 113.2500 mm): Pad 1 [GND] of J5 on F.Cu
[unconnected_items]: Missing connection between items
    Local override; error
    @(115.0000 mm, 114.7500 mm): Pad 4 [GND] of J5 on F.Cu
    @(115.5000 mm, 114.7500 mm): Pad 6 [GND] of J5 on F.Cu
[unconnected_items]: Missing connection between items
    Local override; error
    @(115.5000 mm, 114.7500 mm): Pad 6 [GND] of J5 on F.Cu
    @(116.0000 mm, 114.7500 mm): Pad 8 [GND] of J5 on F.Cu
[unconnected_items]: Missing connection between items
    Local override; error
    @(116.0000 mm, 114.7500 mm): Pad 8 [GND] of J5 on F.Cu
    @(116.5000 mm, 114.7500 mm): Pad 10 [GND] of J5 on F.Cu
[unconnected_items]: Missing connection between items
    Local override; error
    @(116.5000 mm, 95.0000 mm): Pad N6 [GND] of U1 on F.Cu
    @(114.0000 mm, 95.0000 mm): Pad N1 [GND] of U1 on F.Cu
[unconnected_items]: Missing connection between items
    Local override; error
    @(116.5000 mm, 114.7500 mm): Pad 10 [GND] of J5 on F.Cu
    @(117.5000 mm, 114.7500 mm): Pad 14 [GND] of J5 on F.Cu
[unconnected_items]: Missing connection between items
    Local override; error
    @(117.5000 mm, 114.7500 mm): Pad 14 [GND] of J5 on F.Cu
    @(118.5000 mm, 114.7500 mm): Pad 18 [GND] of J5 on F.Cu
[unconnected_items]: Missing connection between items
    Local override; error
    @(118.5000 mm, 113.2500 mm): Pad 17 [GND] of J5 on F.Cu
    @(117.5000 mm, 113.2500 mm): Pad 13 [GND] of J5 on F.Cu
[unconnected_items]: Missing connection between items
    Local override; error
    @(118.5000 mm, 114.7500 mm): Pad 18 [GND] of J5 on F.Cu
    @(119.5000 mm, 114.7500 mm): Pad 22 [GND] of J5 on F.Cu
[unconnected_items]: Missing connection between items
    Local override; error
    @(119.5000 mm, 113.2500 mm): Pad 21 [GND] of J5 on F.Cu
    @(118.5000 mm, 113.2500 mm): Pad 17 [GND] of J5 on F.Cu
[unconnected_items]: Missing connection between items
    Local override; error
    @(119.5000 mm, 114.7500 mm): Pad 22 [GND] of J5 on F.Cu
    @(120.5000 mm, 114.7500 mm): Pad 26 [GND] of J5 on F.Cu
[unconnected_items]: Missing connection between items
    Local override; error
    @(120.5000 mm, 113.2500 mm): Pad 25 [GND] of J5 on F.Cu
    @(119.5000 mm, 113.2500 mm): Pad 21 [GND] of J5 on F.Cu
[unconnected_items]: Missing connection between items
    Local override; error
    @(120.5000 mm, 113.2500 mm): Pad 25 [GND] of J5 on F.Cu
    @(120.5000 mm, 114.7500 mm): Pad 26 [GND] of J5 on F.Cu
[unconnected_items]: Missing connection between items
    Local override; error
    @(120.5000 mm, 114.7500 mm): Pad 26 [GND] of J5 on F.Cu
    @(121.5000 mm, 114.7500 mm): Pad 30 [GND] of J5 on F.Cu
[unconnected_items]: Missing connection between items
    Local override; error
    @(121.5000 mm, 94.5000 mm): Pad M16 [GND] of U1 on F.Cu
    @(116.5000 mm, 95.0000 mm): Pad N6 [GND] of U1 on F.Cu
[unconnected_items]: Missing connection between items
    Local override; error
    @(122.0000 mm, 94.5000 mm): Pad M17 [GND] of U1 on F.Cu
    @(121.5000 mm, 94.5000 mm): Pad M16 [GND] of U1 on F.Cu
[unconnected_items]: Missing connection between items
    Local override; error
    @(122.0000 mm, 94.5000 mm): Pad M17 [GND] of U1 on F.Cu
    @(130.4800 mm, 92.0000 mm): Pad 2 [GND] of C4 on F.Cu
[unconnected_items]: Missing connection between items
    Local override; error
    @(130.4800 mm, 92.0000 mm): Pad 2 [GND] of C4 on F.Cu
    @(128.4800 mm, 86.0000 mm): Pad 2 [GND] of C3 on F.Cu
[unconnected_items]: Missing connection between items
    Local override; error
    @(130.4800 mm, 98.0000 mm): Pad 2 [GND] of R5 on F.Cu
    @(130.4800 mm, 92.0000 mm): Pad 2 [GND] of C4 on F.Cu
[unconnected_items]: Missing connection between items
    Local override; error
    @(117.0000 mm, 113.2500 mm): Pad 11 [MISO1_A] of J5 on F.Cu
    @(120.5000 mm, 95.0000 mm): Pad N14 [MISO1_A] of U1 on F.Cu
[unconnected_items]: Missing connection between items
    Local override; error
    @(117.0000 mm, 95.0000 mm): Pad N7 [MISO1_B] of U1 on F.Cu
    @(117.0000 mm, 114.7500 mm): Pad 12 [MISO1_B] of J5 on F.Cu
[unconnected_items]: Missing connection between items
    Local override; error
    @(115.5000 mm, 113.2500 mm): Pad 5 [MOSI] of J5 on F.Cu
    @(119.5000 mm, 95.0000 mm): Pad N12 [MOSI] of U1 on F.Cu
[unconnected_items]: Missing connection between items
    Local override; error
    @(122.0000 mm, 95.0000 mm): Pad N17 [Net-(U1-ADC_ref)] of U1 on F.Cu
    @(129.5200 mm, 92.0000 mm): Pad 1 [Net-(U1-ADC_ref)] of C4 on F.Cu
[unconnected_items]: Missing connection between items
    Local override; error
    @(122.0000 mm, 89.0000 mm): Pad A17 [Net-(U1-ref_elec)] of U1 on F.Cu
    @(129.5200 mm, 98.0000 mm): Pad 1 [Net-(U1-ref_elec)] of R5 on F.Cu
[unconnected_items]: Missing connection between items
    Local override; error
    @(115.0000 mm, 113.2500 mm): Pad 3 [SCLK] of J5 on F.Cu
    @(118.5000 mm, 95.0000 mm): Pad N10 [SCLK] of U1 on F.Cu
[unconnected_items]: Missing connection between items
    Local override; error
    @(105.0500 mm, 86.9500 mm): Pad 1 [VCC] of U2 on F.Cu
    @(106.9500 mm, 86.9500 mm): Pad 3 [VCC] of U2 on F.Cu
[unconnected_items]: Missing connection between items
    Local override; error
    @(105.0500 mm, 86.9500 mm): Pad 1 [VCC] of U2 on F.Cu
    @(102.5200 mm, 86.0000 mm): Pad 1 [VCC] of C1 on F.Cu
[unconnected_items]: Missing connection between items
    Local override; error
    @(119.0000 mm, 113.2500 mm): Pad 19 [VCC] of J5 on F.Cu
    @(120.0000 mm, 113.2500 mm): Pad 23 [VCC] of J5 on F.Cu
[unconnected_items]: Missing connection between items
    Local override; error
    @(119.0000 mm, 113.2500 mm): Pad 19 [VCC] of J5 on F.Cu
    @(119.0000 mm, 114.7500 mm): Pad 20 [VCC] of J5 on F.Cu
[unconnected_items]: Missing connection between items
    Local override; error
    @(119.0000 mm, 113.2500 mm): Pad 19 [VCC] of J5 on F.Cu
    @(106.9500 mm, 86.9500 mm): Pad 3 [VCC] of U2 on F.Cu
[unconnected_items]: Missing connection between items
    Local override; error
    @(119.0000 mm, 114.7500 mm): Pad 20 [VCC] of J5 on F.Cu
    @(120.0000 mm, 114.7500 mm): Pad 24 [VCC] of J5 on F.Cu

** Found 0 Footprint errors **

** End of Report **

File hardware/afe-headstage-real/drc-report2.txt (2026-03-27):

** Drc report for afe-headstage-real.kicad_pcb **
** Created on 2026-02-18T15:32:20-0500 **

** Found 14 DRC violations **
[lib_footprint_issues]: Footprint 'BGA-196_9.0x7.0mm_Layout14x14_P0.5mm' not found in library 'Package_BGA'.
    Local override; warning
    @(118.0000 mm, 92.0000 mm): Footprint U1
[lib_footprint_mismatch]: Footprint 'SOT-23-5' does not match copy in library 'Package_TO_SOT_SMD'.
    Local override; warning
    @(106.0000 mm, 86.0000 mm): Footprint U2
[lib_footprint_issues]: Footprint 'Samtec_QSH-030-01-x-D-A_2x15_P0.50mm' not found in library 'Connector_Samtec'.
    Local override; warning
    @(118.0000 mm, 114.0000 mm): Footprint J5
[lib_footprint_mismatch]: Footprint 'R_0402_1005Metric' does not match copy in library 'Resistor_SMD'.
    Local override; warning
    @(103.0000 mm, 86.0000 mm): Footprint C1
[lib_footprint_mismatch]: Footprint 'R_0402_1005Metric' does not match copy in library 'Resistor_SMD'.
    Local override; warning
    @(110.0000 mm, 86.0000 mm): Footprint C2
[lib_footprint_mismatch]: Footprint 'R_0402_1005Metric' does not match copy in library 'Resistor_SMD'.
    Local override; warning
    @(128.0000 mm, 86.0000 mm): Footprint C3
[lib_footprint_mismatch]: Footprint 'R_0402_1005Metric' does not match copy in library 'Resistor_SMD'.
    Local override; warning
    @(130.0000 mm, 92.0000 mm): Footprint C4
[lib_footprint_mismatch]: Footprint 'R_0402_1005Metric' does not match copy in library 'Resistor_SMD'.
    Local override; warning
    @(114.0000 mm, 86.0000 mm): Footprint C5
[lib_footprint_mismatch]: Footprint 'R_0402_1005Metric' does not match copy in library 'Resistor_SMD'.
    Local override; warning
    @(122.0000 mm, 86.0000 mm): Footprint FB1
[lib_footprint_mismatch]: Footprint 'R_0402_1005Metric' does not match copy in library 'Resistor_SMD'.
    Local override; warning
    @(106.0000 mm, 94.0000 mm): Footprint R1
[lib_footprint_mismatch]: Footprint 'R_0402_1005Metric' does not match copy in library 'Resistor_SMD'.
    Local override; warning
    @(106.0000 mm, 97.0000 mm): Footprint R2
[lib_footprint_mismatch]: Footprint 'R_0402_1005Metric' does not match copy in library 'Resistor_SMD'.
    Local override; warning
    @(106.0000 mm, 100.0000 mm): Footprint R3
[lib_footprint_mismatch]: Footprint 'R_0402_1005Metric' does not match copy in library 'Resistor_SMD'.
    Local override; warning
    @(106.0000 mm, 103.0000 mm): Footprint R4
[lib_footprint_mismatch]: Footprint 'R_0402_1005Metric' does not match copy in library 'Resistor_SMD'.
    Local override; warning
    @(130.0000 mm, 98.0000 mm): Footprint R5

** Found 54 unconnected pads **
[unconnected_items]: Missing connection between items
    Local override; error
    @(105.0500 mm, 85.0500 mm): Pad 5 [+3V3] of U2 on F.Cu
    @(109.5200 mm, 86.0000 mm): Pad 1 [+3V3] of C2 on F.Cu
[unconnected_items]: Missing connection between items
    Local override; error
    @(109.5200 mm, 86.0000 mm): Pad 1 [+3V3] of C2 on F.Cu
    @(113.5200 mm, 86.0000 mm): Pad 1 [+3V3] of C5 on F.Cu
[unconnected_items]: Missing connection between items
    Local override; error
    @(114.5000 mm, 95.0000 mm): Pad N2 [+3V3] of U1 on F.Cu
    @(121.0000 mm, 95.0000 mm): Pad N15 [+3V3] of U1 on F.Cu
[unconnected_items]: Missing connection between items
    Local override; error
    @(121.0000 mm, 94.5000 mm): Pad M15 [+3V3] of U1 on F.Cu
    @(121.0000 mm, 95.0000 mm): Pad N15 [+3V3] of U1 on F.Cu
[unconnected_items]: Missing connection between items
    Local override; error
    @(122.4800 mm, 86.0000 mm): Pad 2 [+3V3] of FB1 on F.Cu
    @(121.0000 mm, 94.5000 mm): Pad M15 [+3V3] of U1 on F.Cu
[unconnected_items]: Missing connection between items
    Local override; error
    @(122.4800 mm, 86.0000 mm): Pad 2 [+3V3] of FB1 on F.Cu
    @(113.5200 mm, 86.0000 mm): Pad 1 [+3V3] of C5 on F.Cu
[unconnected_items]: Missing connection between items
    Local override; error
    @(105.5200 mm, 94.0000 mm): Pad 1 [/CH0] of R1 on F.Cu
    @(114.0000 mm, 89.0000 mm): Pad A1 [/CH0] of U1 on F.Cu
[unconnected_items]: Missing connection between items
    Local override; error
    @(105.5200 mm, 97.0000 mm): Pad 1 [/CH1] of R2 on F.Cu
    @(114.5000 mm, 89.0000 mm): Pad A2 [/CH1] of U1 on F.Cu
[unconnected_items]: Missing connection between items
    Local override; error
    @(105.5200 mm, 100.0000 mm): Pad 1 [/CH2] of R3 on F.Cu
    @(115.0000 mm, 89.0000 mm): Pad A3 [/CH2] of U1 on F.Cu
[unconnected_items]: Missing connection between items
    Local override; error
    @(105.5200 mm, 103.0000 mm): Pad 1 [/CH3] of R4 on F.Cu
    @(115.5000 mm, 89.0000 mm): Pad A4 [/CH3] of U1 on F.Cu
[unconnected_items]: Missing connection between items
    Local override; error
    @(121.5200 mm, 86.0000 mm): Pad 1 [/DVDD_AFE] of FB1 on F.Cu
    @(127.5200 mm, 86.0000 mm): Pad 1 [/DVDD_AFE] of C3 on F.Cu
[unconnected_items]: Missing connection between items
    Local override; error
    @(116.0000 mm, 113.2500 mm): Pad 7 [CS1] of J5 on F.Cu
    @(117.5000 mm, 95.0000 mm): Pad N8 [CS1] of U1 on F.Cu
[unconnected_items]: Missing connection between items
    Local override; error
    @(106.0000 mm, 86.9500 mm): Pad 2 [GND] of U2 on F.Cu
    @(103.4800 mm, 86.0000 mm): Pad 2 [GND] of C1 on F.Cu
[unconnected_items]: Missing connection between items
    Local override; error
    @(106.0000 mm, 86.9500 mm): Pad 2 [GND] of U2 on F.Cu
    @(106.4800 mm, 94.0000 mm): Pad 2 [GND] of R1 on F.Cu
[unconnected_items]: Missing connection between items
    Local override; error
    @(106.4800 mm, 97.0000 mm): Pad 2 [GND] of R2 on F.Cu
    @(106.4800 mm, 94.0000 mm): Pad 2 [GND] of R1 on F.Cu
[unconnected_items]: Missing connection between items
    Local override; error
    @(106.4800 mm, 100.0000 mm): Pad 2 [GND] of R3 on F.Cu
    @(106.4800 mm, 97.0000 mm): Pad 2 [GND] of R2 on F.Cu
[unconnected_items]: Missing connection between items
    Local override; error
    @(106.4800 mm, 103.0000 mm): Pad 2 [GND] of R4 on F.Cu
    @(106.4800 mm, 100.0000 mm): Pad 2 [GND] of R3 on F.Cu
[unconnected_items]: Missing connection between items
    Local override; error
    @(110.4800 mm, 86.0000 mm): Pad 2 [GND] of C2 on F.Cu
    @(106.0000 mm, 86.9500 mm): Pad 2 [GND] of U2 on F.Cu
[unconnected_items]: Missing connection between items
    Local override; error
    @(114.0000 mm, 94.0000 mm): Pad L1 [GND] of U1 on F.Cu
    @(114.0000 mm, 95.0000 mm): Pad N1 [GND] of U1 on F.Cu
[unconnected_items]: Missing connection between items
    Local override; error
    @(114.0000 mm, 94.0000 mm): Pad L1 [GND] of U1 on F.Cu
    @(106.4800 mm, 94.0000 mm): Pad 2 [GND] of R1 on F.Cu
[unconnected_items]: Missing connection between items
    Local override; error
    @(114.4800 mm, 86.0000 mm): Pad 2 [GND] of C5 on F.Cu
    @(110.4800 mm, 86.0000 mm): Pad 2 [GND] of C2 on F.Cu
[unconnected_items]: Missing connection between items
    Local override; error
    @(114.5000 mm, 113.2500 mm): Pad 1 [GND] of J5 on F.Cu
    @(106.4800 mm, 103.0000 mm): Pad 2 [GND] of R4 on F.Cu
[unconnected_items]: Missing connection between items
    Local override; error
    @(114.5000 mm, 114.7500 mm): Pad 2 [GND] of J5 on F.Cu
    @(115.0000 mm, 114.7500 mm): Pad 4 [GND] of J5 on F.Cu
[unconnected_items]: Missing connection between items
    Local override; error
    @(114.5000 mm, 114.7500 mm): Pad 2 [GND] of J5 on F.Cu
    @(114.5000 mm, 113.2500 mm): Pad 1 [GND] of J5 on F.Cu
[unconnected_items]: Missing connection between items
    Local override; error
    @(115.0000 mm, 114.7500 mm): Pad 4 [GND] of J5 on F.Cu
    @(115.5000 mm, 114.7500 mm): Pad 6 [GND] of J5 on F.Cu
[unconnected_items]: Missing connection between items
    Local override; error
    @(115.5000 mm, 114.7500 mm): Pad 6 [GND] of J5 on F.Cu
    @(116.0000 mm, 114.7500 mm): Pad 8 [GND] of J5 on F.Cu
[unconnected_items]: Missing connection between items
    Local override; error
    @(116.0000 mm, 114.7500 mm): Pad 8 [GND] of J5 on F.Cu
    @(116.5000 mm, 114.7500 mm): Pad 10 [GND] of J5 on F.Cu
[unconnected_items]: Missing connection between items
    Local override; error
    @(116.5000 mm, 95.0000 mm): Pad N6 [GND] of U1 on F.Cu
    @(114.0000 mm, 95.0000 mm): Pad N1 [GND] of U1 on F.Cu
[unconnected_items]: Missing connection between items
    Local override; error
    @(116.5000 mm, 114.7500 mm): Pad 10 [GND] of J5 on F.Cu
    @(117.5000 mm, 114.7500 mm): Pad 14 [GND] of J5 on F.Cu
[unconnected_items]: Missing connection between items
    Local override; error
    @(117.5000 mm, 114.7500 mm): Pad 14 [GND] of J5 on F.Cu
    @(118.5000 mm, 114.7500 mm): Pad 18 [GND] of J5 on F.Cu
[unconnected_items]: Missing connection between items
    Local override; error
    @(118.5000 mm, 113.2500 mm): Pad 17 [GND] of J5 on F.Cu
    @(117.5000 mm, 113.2500 mm): Pad 13 [GND] of J5 on F.Cu
[unconnected_items]: Missing connection between items
    Local override; error
    @(118.5000 mm, 114.7500 mm): Pad 18 [GND] of J5 on F.Cu
    @(119.5000 mm, 114.7500 mm): Pad 22 [GND] of J5 on F.Cu
[unconnected_items]: Missing connection between items
    Local override; error
    @(119.5000 mm, 113.2500 mm): Pad 21 [GND] of J5 on F.Cu
    @(118.5000 mm, 113.2500 mm): Pad 17 [GND] of J5 on F.Cu
[unconnected_items]: Missing connection between items
    Local override; error
    @(119.5000 mm, 114.7500 mm): Pad 22 [GND] of J5 on F.Cu
    @(120.5000 mm, 114.7500 mm): Pad 26 [GND] of J5 on F.Cu
[unconnected_items]: Missing connection between items
    Local override; error
    @(120.5000 mm, 113.2500 mm): Pad 25 [GND] of J5 on F.Cu
    @(119.5000 mm, 113.2500 mm): Pad 21 [GND] of J5 on F.Cu
[unconnected_items]: Missing connection between items
    Local override; error
    @(120.5000 mm, 113.2500 mm): Pad 25 [GND] of J5 on F.Cu
    @(120.5000 mm, 114.7500 mm): Pad 26 [GND] of J5 on F.Cu
[unconnected_items]: Missing connection between items
    Local override; error
    @(120.5000 mm, 114.7500 mm): Pad 26 [GND] of J5 on F.Cu
    @(121.5000 mm, 114.7500 mm): Pad 30 [GND] of J5 on F.Cu
[unconnected_items]: Missing connection between items
    Local override; error
    @(121.5000 mm, 94.5000 mm): Pad M16 [GND] of U1 on F.Cu
    @(116.5000 mm, 95.0000 mm): Pad N6 [GND] of U1 on F.Cu
[unconnected_items]: Missing connection between items
    Local override; error
    @(122.0000 mm, 94.5000 mm): Pad M17 [GND] of U1 on F.Cu
    @(121.5000 mm, 94.5000 mm): Pad M16 [GND] of U1 on F.Cu
[unconnected_items]: Missing connection between items
    Local override; error
    @(122.0000 mm, 94.5000 mm): Pad M17 [GND] of U1 on F.Cu
    @(130.4800 mm, 92.0000 mm): Pad 2 [GND] of C4 on F.Cu
[unconnected_items]: Missing connection between items
    Local override; error
    @(130.4800 mm, 92.0000 mm): Pad 2 [GND] of C4 on F.Cu
    @(128.4800 mm, 86.0000 mm): Pad 2 [GND] of C3 on F.Cu
[unconnected_items]: Missing connection between items
    Local override; error
    @(130.4800 mm, 98.0000 mm): Pad 2 [GND] of R5 on F.Cu
    @(130.4800 mm, 92.0000 mm): Pad 2 [GND] of C4 on F.Cu
[unconnected_items]: Missing connection between items
    Local override; error
    @(117.0000 mm, 113.2500 mm): Pad 11 [MISO1_A] of J5 on F.Cu
    @(120.5000 mm, 95.0000 mm): Pad N14 [MISO1_A] of U1 on F.Cu
[unconnected_items]: Missing connection between items
    Local override; error
    @(117.0000 mm, 95.0000 mm): Pad N7 [MISO1_B] of U1 on F.Cu
    @(117.0000 mm, 114.7500 mm): Pad 12 [MISO1_B] of J5 on F.Cu
[unconnected_items]: Missing connection between items
    Local override; error
    @(115.5000 mm, 113.2500 mm): Pad 5 [MOSI] of J5 on F.Cu
    @(119.5000 mm, 95.0000 mm): Pad N12 [MOSI] of U1 on F.Cu
[unconnected_items]: Missing connection between items
    Local override; error
    @(122.0000 mm, 95.0000 mm): Pad N17 [Net-(U1-ADC_ref)] of U1 on F.Cu
    @(129.5200 mm, 92.0000 mm): Pad 1 [Net-(U1-ADC_ref)] of C4 on F.Cu
[unconnected_items]: Missing connection between items
    Local override; error
    @(122.0000 mm, 89.0000 mm): Pad A17 [Net-(U1-ref_elec)] of U1 on F.Cu
    @(129.5200 mm, 98.0000 mm): Pad 1 [Net-(U1-ref_elec)] of R5 on F.Cu
[unconnected_items]: Missing connection between items
    Local override; error
    @(115.0000 mm, 113.2500 mm): Pad 3 [SCLK] of J5 on F.Cu
    @(118.5000 mm, 95.0000 mm): Pad N10 [SCLK] of U1 on F.Cu
[unconnected_items]: Missing connection between items
    Local override; error
    @(105.0500 mm, 86.9500 mm): Pad 1 [VCC] of U2 on F.Cu
    @(106.9500 mm, 86.9500 mm): Pad 3 [VCC] of U2 on F.Cu
[unconnected_items]: Missing connection between items
    Local override; error
    @(105.0500 mm, 86.9500 mm): Pad 1 [VCC] of U2 on F.Cu
    @(102.5200 mm, 86.0000 mm): Pad 1 [VCC] of C1 on F.Cu
[unconnected_items]: Missing connection between items
    Local override; error
    @(119.0000 mm, 113.2500 mm): Pad 19 [VCC] of J5 on F.Cu
    @(120.0000 mm, 113.2500 mm): Pad 23 [VCC] of J5 on F.Cu
[unconnected_items]: Missing connection between items
    Local override; error
    @(119.0000 mm, 113.2500 mm): Pad 19 [VCC] of J5 on F.Cu
    @(119.0000 mm, 114.7500 mm): Pad 20 [VCC] of J5 on F.Cu
[unconnected_items]: Missing connection between items
    Local override; error
    @(119.0000 mm, 113.2500 mm): Pad 19 [VCC] of J5 on F.Cu
    @(106.9500 mm, 86.9500 mm): Pad 3 [VCC] of U2 on F.Cu
[unconnected_items]: Missing connection between items
    Local override; error
    @(119.0000 mm, 114.7500 mm): Pad 20 [VCC] of J5 on F.Cu
    @(120.0000 mm, 114.7500 mm): Pad 24 [VCC] of J5 on F.Cu

** Found 0 Footprint errors **

** End of Report **

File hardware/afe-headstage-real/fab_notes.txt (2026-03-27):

================================================================================
 FABRICATION NOTES — AFE Headstage v1
 Part Number:  afe-headstage-v1
 Revision:     1.0
 Date:         2026-03-01
 Contact:      [engineer email]
================================================================================

1. BOARD SPECIFICATION
----------------------
  Layers:                4 (F.Cu / In1.Cu / In2.Cu / B.Cu)
  Finished thickness:    1.6 mm ±10%
  Copper weight outer:   1 oz (35 µm) — F.Cu and B.Cu
  Copper weight inner:   1 oz (35 µm) — In1.Cu and In2.Cu
  Dielectric:            FR4, Tg ≥ 150 °C
  Board dimensions:      30.0 × 24.0 mm
  Surface finish:        ENIG
  Soldermask:            Both sides, green
  Silkscreen:            Front side only, white

  No material substitutions without written approval.

2. DESIGN RULES
---------------
  Minimum trace width:   0.15 mm
  Minimum clearance:     0.20 mm
  Minimum finished PTH drill: 0.20 mm
  Maximum via aspect ratio:   8:1
  All plated holes are through-hole. No blind or buried vias.

3. SOLDERMASK & VIA TENTING
----------------------------
  All non-VIP vias shall be soldermask tented both sides.

  CLAUSE SM-1: DO NOT MODIFY SOLDERMASK EXPANSION RULES.
  Mask openings over J5 pads shall remain as provided in Gerbers.
  Do not auto-adjust or override mask openings on any pad or via.

  EXCEPTION: Via-in-pad vias at J5 — see Section 4.

  CLAUSE SM-2: U1 THERMAL VIAS — COMPONENT-SIDE TENTING REQUIRED.
  The 9 thermal vias (0.30 mm drill) under U1 QFN-56 exposed pad sit
  inside the mask opening for the exposed pad.  These vias MUST be
  soldermask tented on the component side (F.Cu) to prevent solder
  paste from wicking into the via barrels during reflow.
  Gerber data includes tenting flags on these vias — do not remove.
  Bottom side (B.Cu) tenting is also specified in Gerbers; preserve it.
  Do not open mask over U1 thermal vias on either side.
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

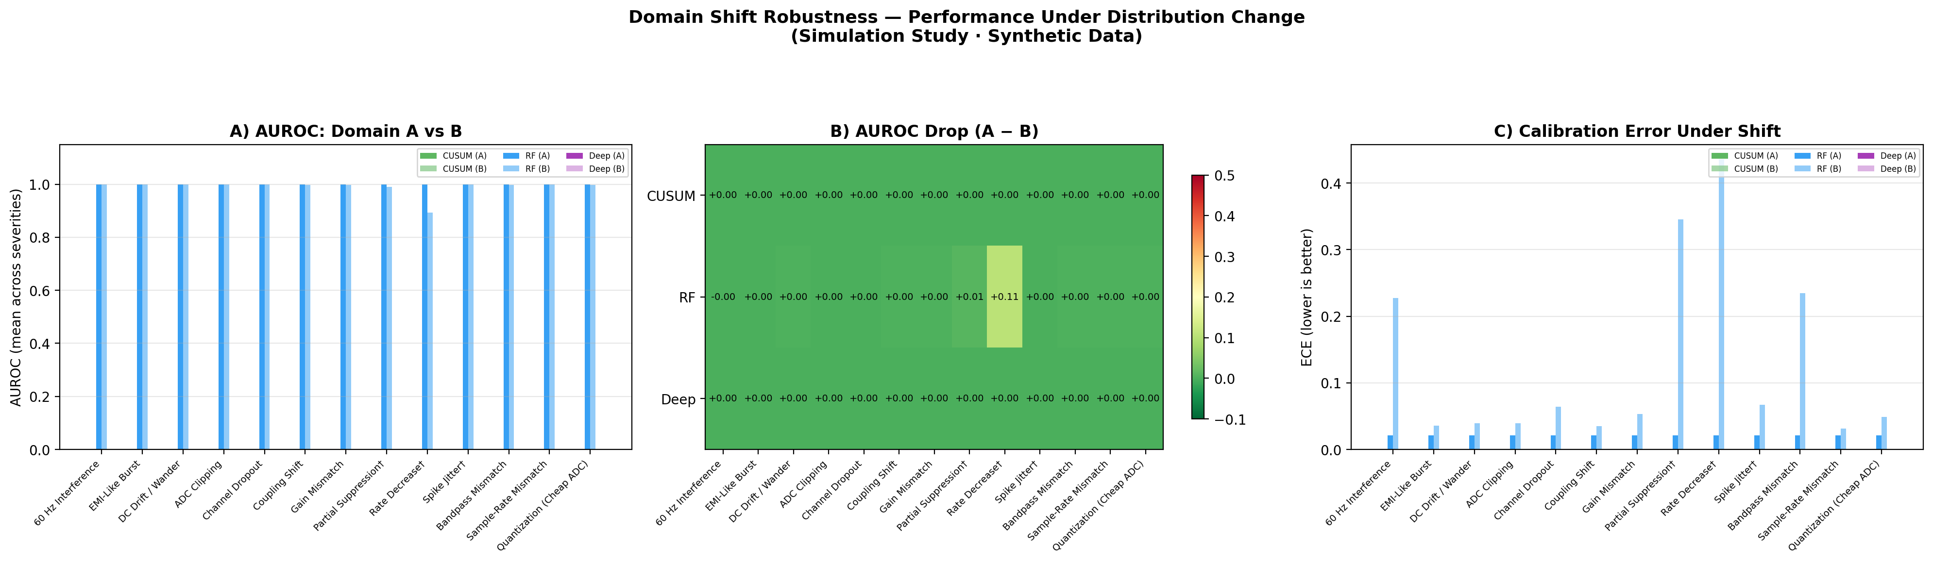
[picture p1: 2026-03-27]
out/ds_rf_report/fig_domain_shift.png

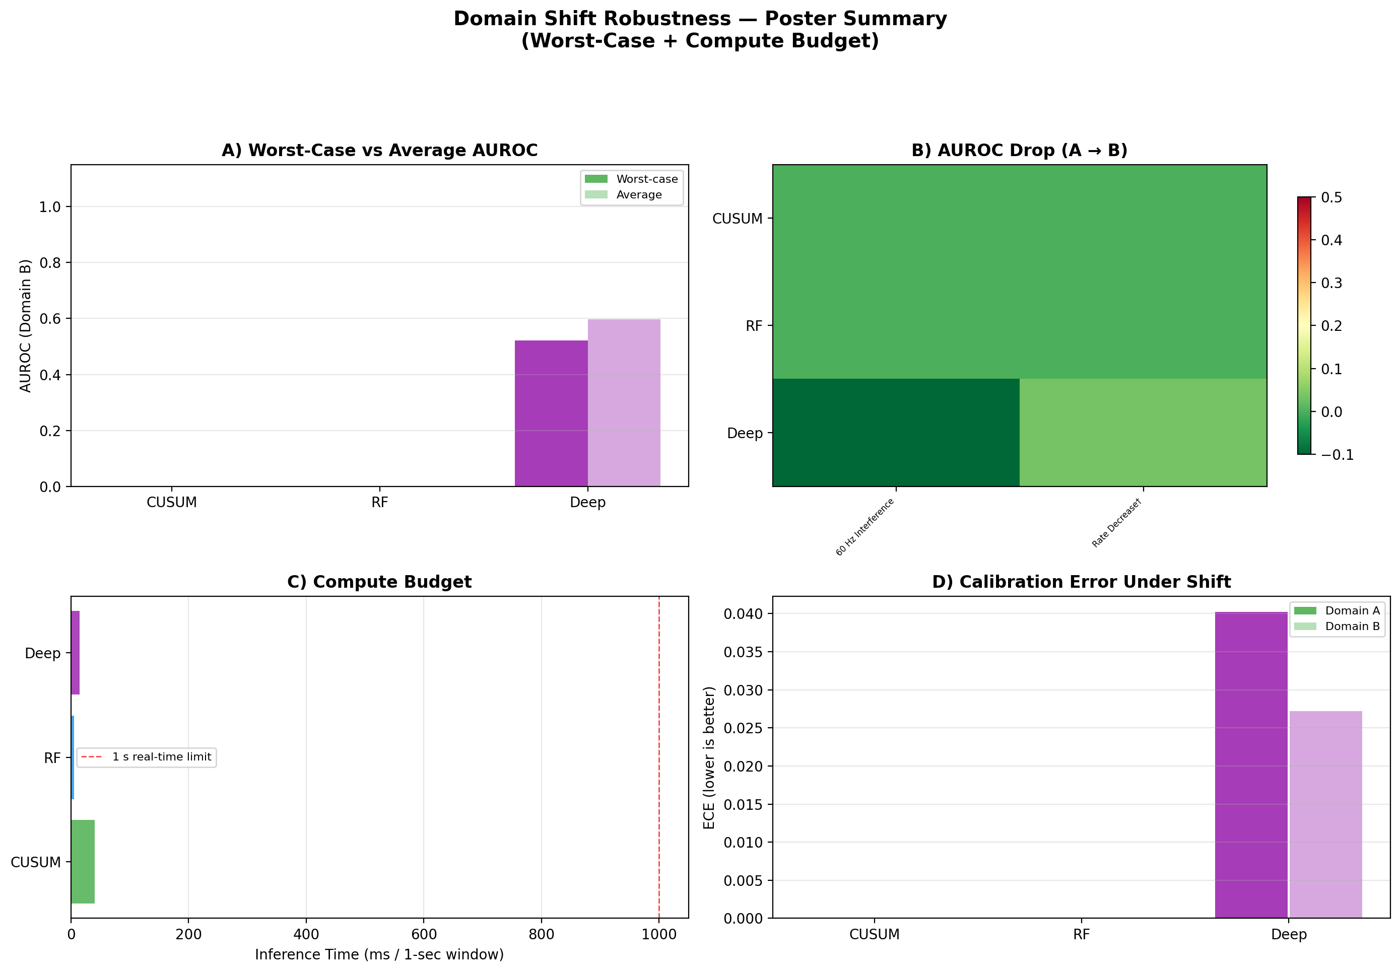
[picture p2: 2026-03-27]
out/ds_deep_smoke/poster_pack/poster_fig.png

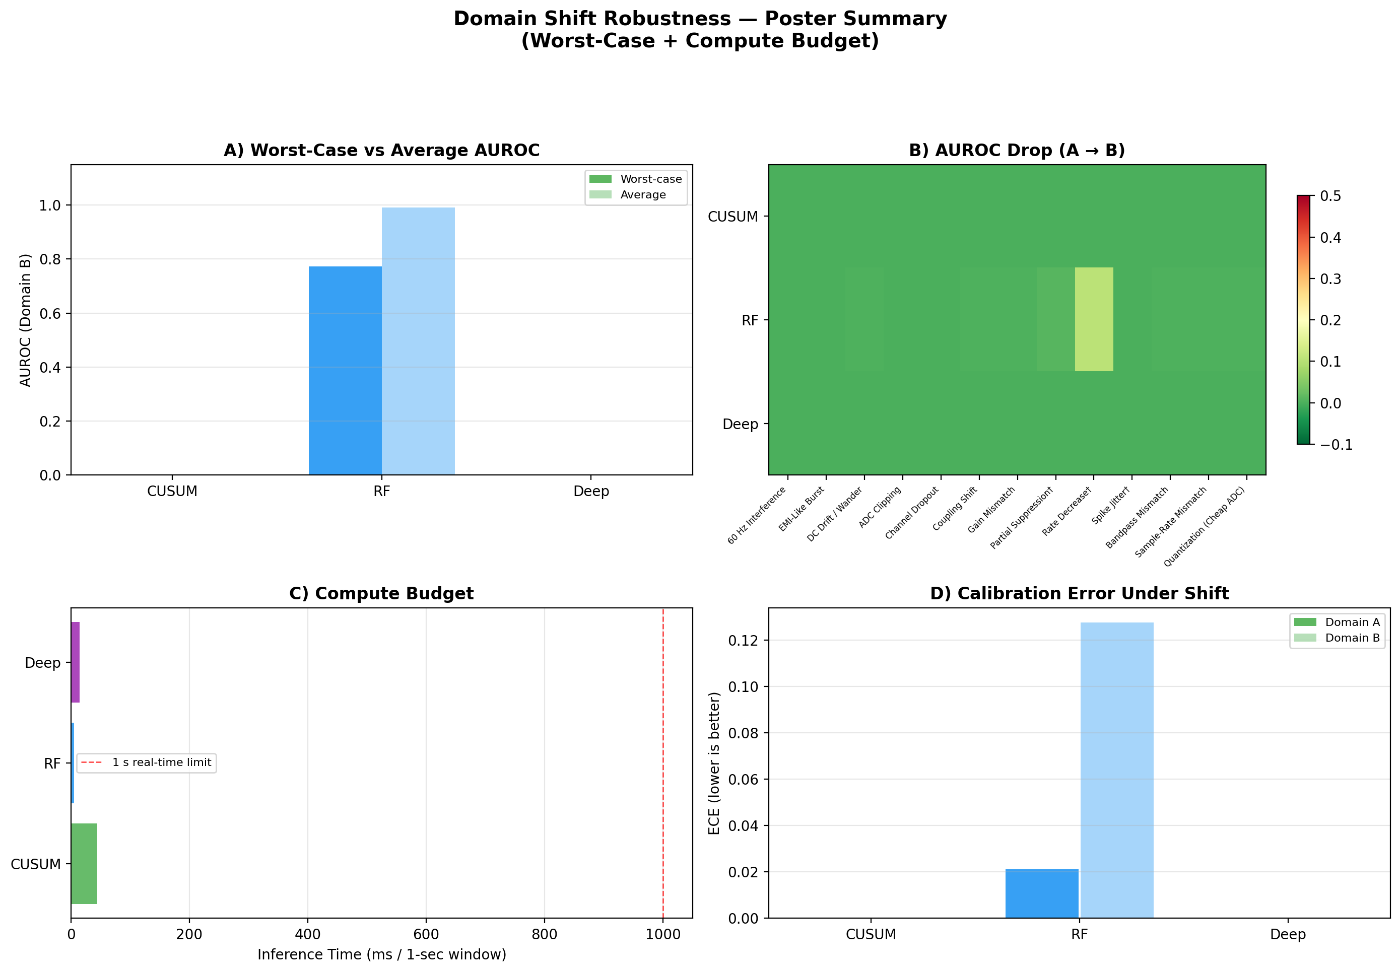
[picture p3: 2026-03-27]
out/ds_rf_report/poster_pack/poster_fig.png

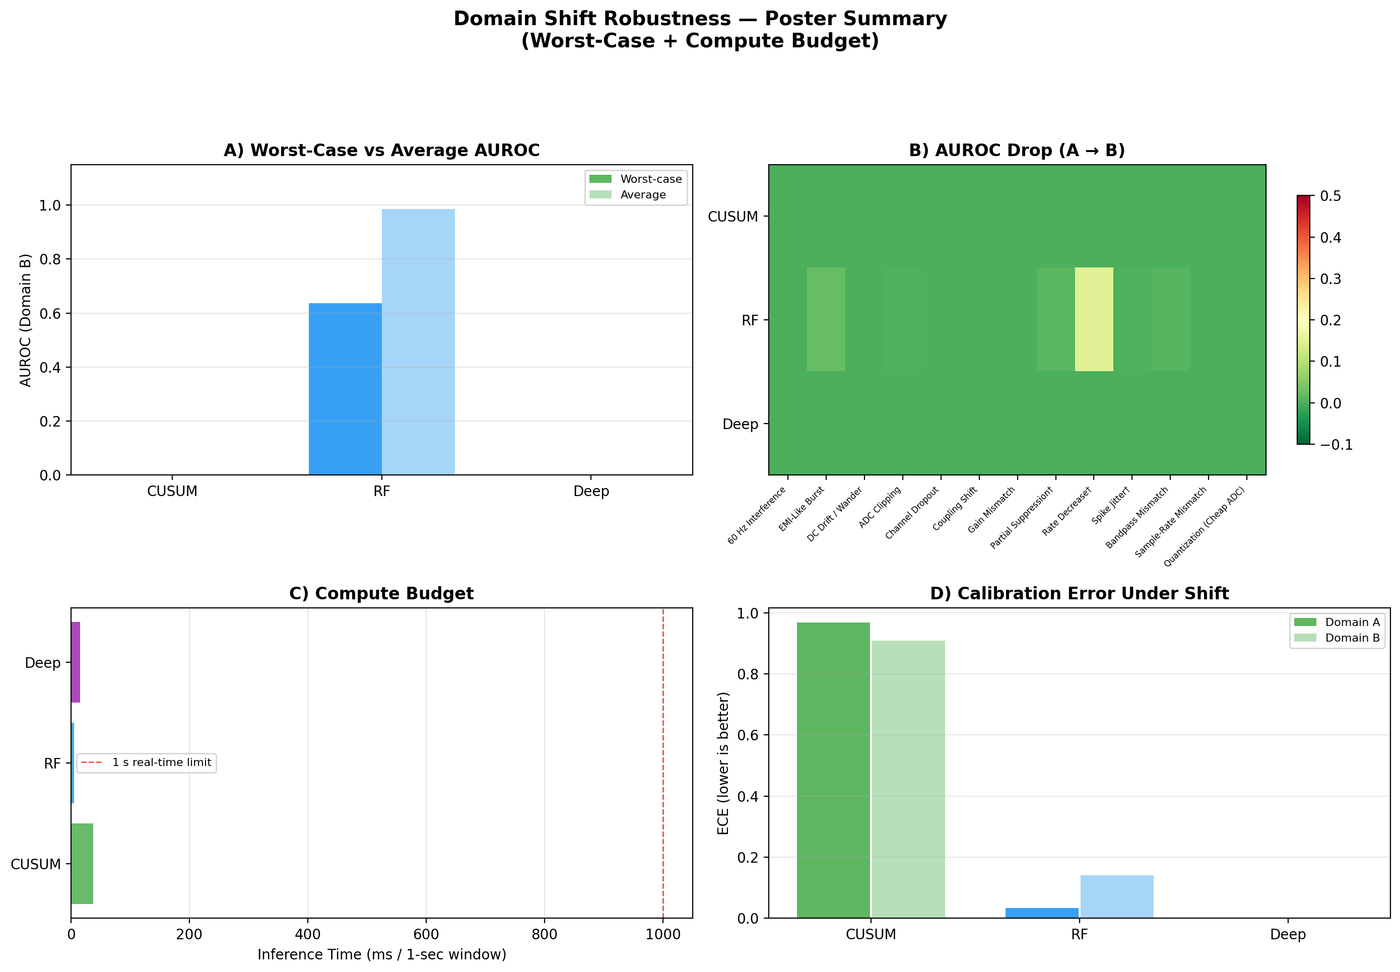
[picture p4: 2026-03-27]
out/ds_demo/poster_pack/poster_fig.png

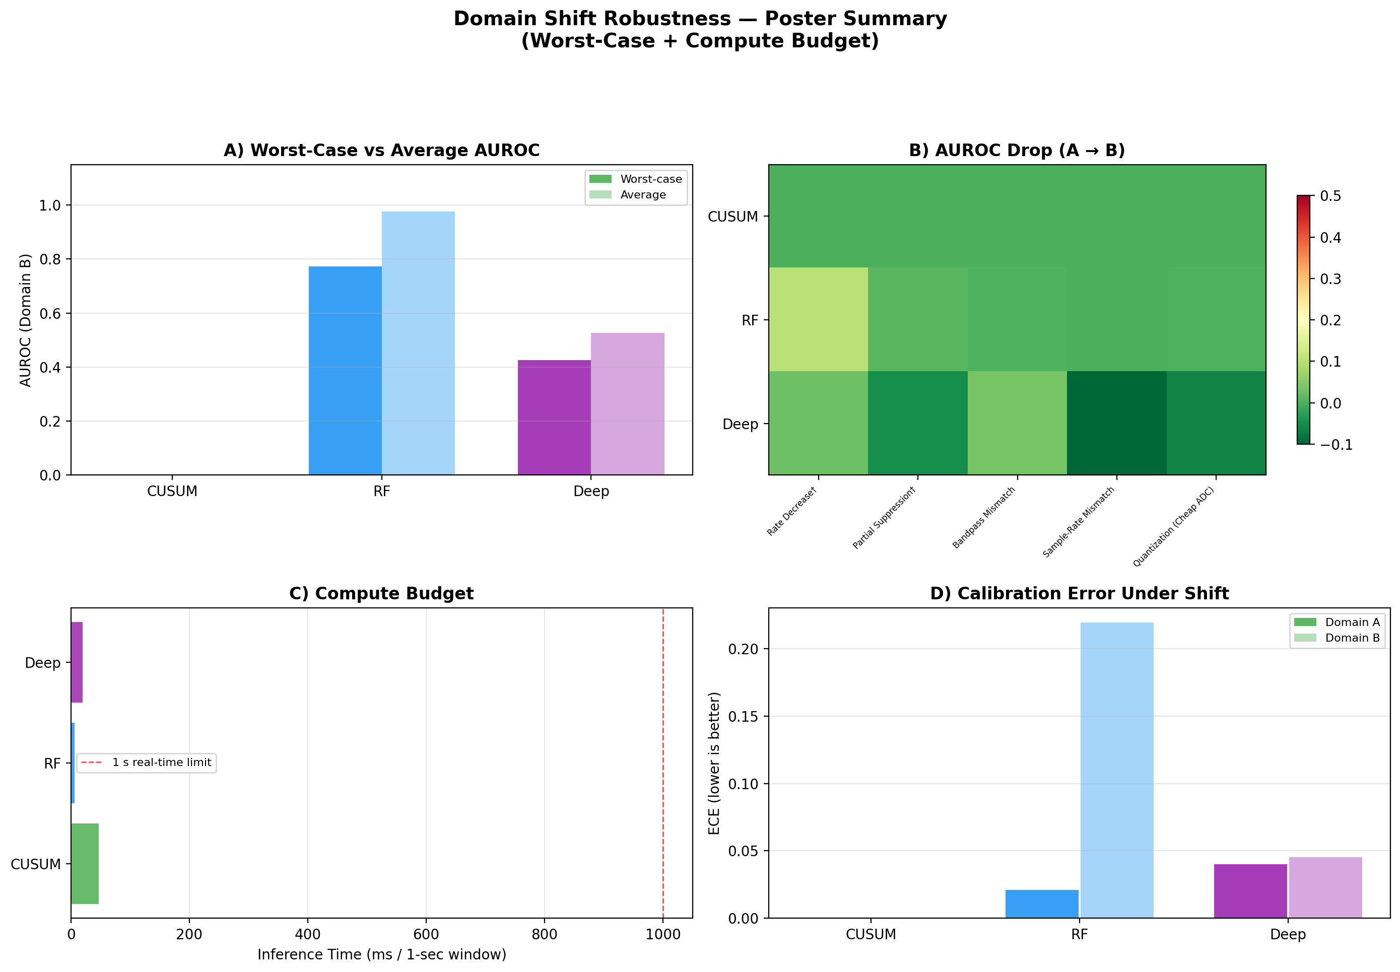
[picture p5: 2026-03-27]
out/ds_ablation/poster_pack/poster_fig.png

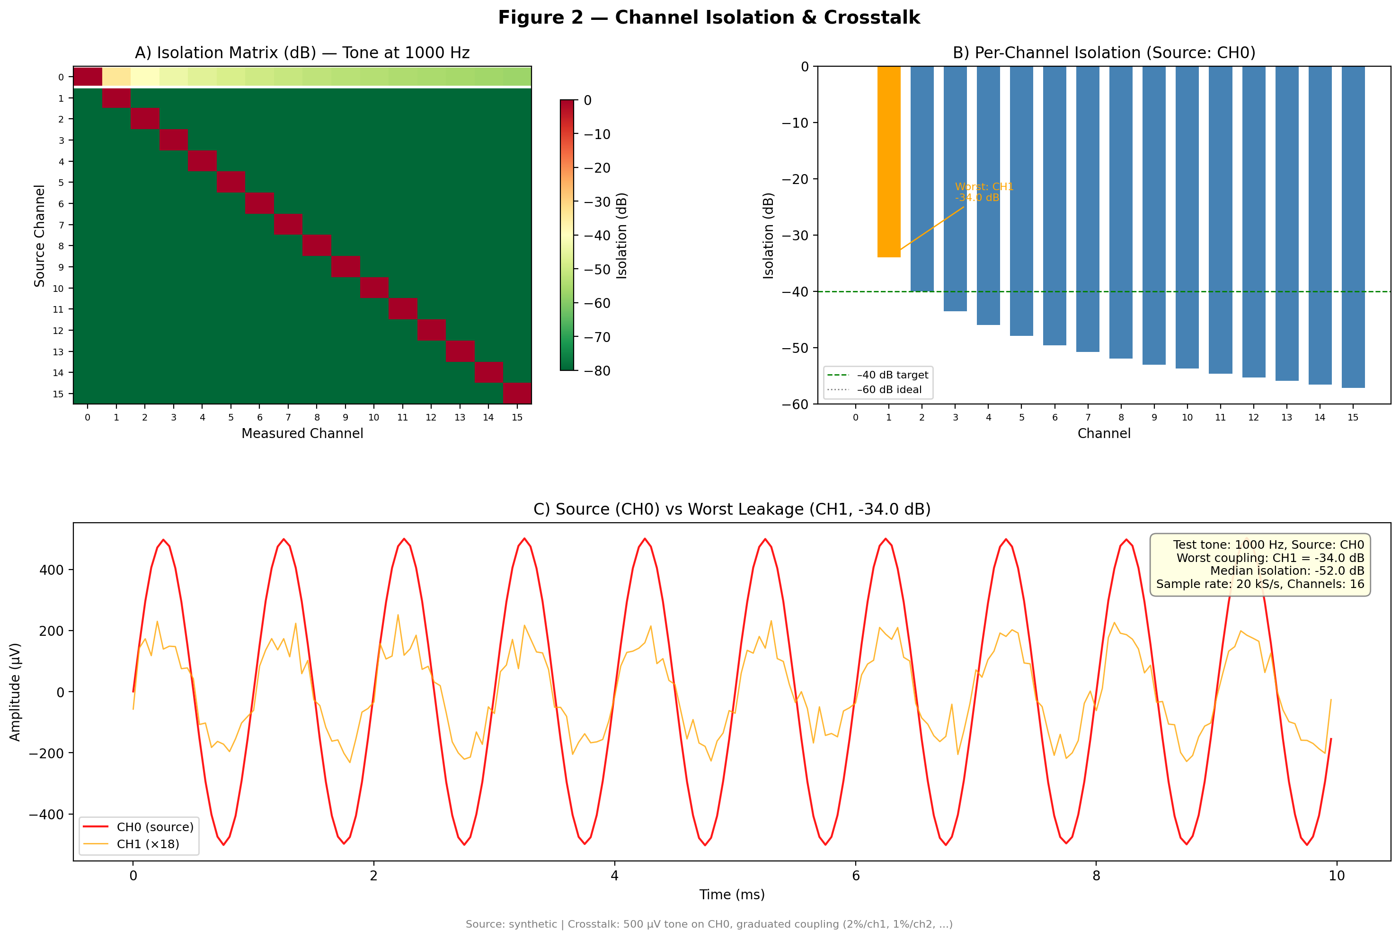
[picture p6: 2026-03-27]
analysis/out/figures/fig2_crosstalk.png

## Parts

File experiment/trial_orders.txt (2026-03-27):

============================================================
  PHANTOM VALIDATION — TRIAL ORDER SHEETS
  Print this and bring to the bench.
============================================================

────────────────────────────────────────────────────────────
  SESSION 0
────────────────────────────────────────────────────────────
    #  Type         Level      Filename                             Temp
  ───  ──────────── ────────── ─────────────────────────────────── ─────
    1  baseline     none       S0_T01_baseline_none.rhd            _____
    2  baseline     none       S0_T02_baseline_none.rhd            _____
    3  baseline     none       S0_T03_baseline_none.rhd            _____
    4  baseline     none       S0_T04_baseline_none.rhd            _____
    5  baseline     none       S0_T05_baseline_none.rhd            _____

────────────────────────────────────────────────────────────
  SESSION 1
────────────────────────────────────────────────────────────
    #  Type         Level      Filename                             Temp
  ───  ──────────── ────────── ─────────────────────────────────── ─────
    1  impedance    0.3pct     S1_T01_impedance_0.3pct.rhd         _____
    2  impedance    0.1pct     S1_T02_impedance_0.1pct.rhd         _____
    3  impedance    0.3pct     S1_T03_impedance_0.3pct.rhd         _____
    4  impedance    0.3pct     S1_T04_impedance_0.3pct.rhd         _____
    5  impedance    0.1pct     S1_T05_impedance_0.1pct.rhd         _____
    6  impedance    0.1pct     S1_T06_impedance_0.1pct.rhd         _____
    7  impedance    0.3pct     S1_T07_impedance_0.3pct.rhd         _____
    8  impedance    0.9pct     S1_T08_impedance_0.9pct.rhd         _____
    9  impedance    0.3pct     S1_T09_impedance_0.3pct.rhd         _____
   10  impedance    0.9pct     S1_T10_impedance_0.9pct.rhd         _____
   11  impedance    0.9pct     S1_T11_impedance_0.9pct.rhd         _____
   12  impedance    0.1pct     S1_T12_impedance_0.1pct.rhd         _____
   13  impedance    0.9pct     S1_T13_impedance_0.9pct.rhd         _____
   14  impedance    0.9pct     S1_T14_impedance_0.9pct.rhd         _____
   15  impedance    0.1pct     S1_T15_impedance_0.1pct.rhd         _____

────────────────────────────────────────────────────────────
  SESSION 2
────────────────────────────────────────────────────────────
    #  Type         Level      Filename                             Temp
  ───  ──────────── ────────── ─────────────────────────────────── ─────
    1  coupling     1M         S2_T01_coupling_1M.rhd              _____
    2  coupling     10k        S2_T02_coupling_10k.rhd             _____
    3  coupling     100k       S2_T03_coupling_100k.rhd            _____
    4  coupling     100k       S2_T04_coupling_100k.rhd            _____
    5  coupling     1M         S2_T05_coupling_1M.rhd              _____
    6  coupling     100k       S2_T06_coupling_100k.rhd            _____
    7  coupling     100k       S2_T07_coupling_100k.rhd            _____
    8  coupling     10k        S2_T08_coupling_10k.rhd             _____
    9  coupling     10k        S2_T09_coupling_10k.rhd             _____
   10  coupling     100k       S2_T10_coupling_100k.rhd            _____
   11  coupling     10k        S2_T11_coupling_10k.rhd             _____
   12  coupling     1M         S2_T12_coupling_1M.rhd              _____
   13  coupling     1M         S2_T13_coupling_1M.rhd              _____
   14  coupling     10k        S2_T14_coupling_10k.rhd             _____
   15  coupling     1M         S2_T15_coupling_1M.rhd              _____

────────────────────────────────────────────────────────────
  SESSION 3
────────────────────────────────────────────────────────────
    #  Type         Level      Filename                             Temp
  ───  ──────────── ────────── ─────────────────────────────────── ─────
    1  injection    50mV       S3_T01_injection_50mV.rhd           _____
    2  injection    50mV       S3_T02_injection_50mV.rhd           _____
    3  injection    10mV       S3_T03_injection_10mV.rhd           _____
    4  injection    100mV      S3_T04_injection_100mV.rhd          _____
    5  injection    100mV      S3_T05_injection_100mV.rhd          _____
    6  injection    100mV      S3_T06_injection_100mV.rhd          _____
    7  injection    10mV       S3_T07_injection_10mV.rhd           _____
    8  injection    100mV      S3_T08_injection_100mV.rhd          _____
    9  injection    50mV       S3_T09_injection_50mV.rhd           _____
   10  injection    50mV       S3_T10_injection_50mV.rhd           _____
   11  injection    10mV       S3_T11_injection_10mV.rhd           _____
   12  injection    10mV       S3_T12_injection_10mV.rhd           _____
   13  injection    100mV      S3_T13_injection_100mV.rhd          _____
   14  injection    10mV       S3_T14_injection_10mV.rhd           _____
   15  injection    50mV       S3_T15_injection_50mV.rhd           _____

────────────────────────────────────────────────────────────
  SESSION 4
────────────────────────────────────────────────────────────
    #  Type         Level      Filename                             Temp
  ───  ──────────── ────────── ─────────────────────────────────── ─────
    1  impedance    0.1pct     S4_T01_impedance_0.1pct.rhd         _____
    2  impedance    0.3pct     S4_T02_impedance_0.3pct.rhd         _____
    3  injection    10mV       S4_T03_injection_10mV.rhd           _____
    4  impedance    0.1pct     S4_T04_impedance_0.1pct.rhd         _____
    5  coupling     10k        S4_T05_coupling_10k.rhd             _____
    6  injection    50mV       S4_T06_injection_50mV.rhd           _____
    7  injection    100mV      S4_T07_injection_100mV.rhd          _____
    8  impedance    0.9pct     S4_T08_impedance_0.9pct.rhd         _____
    9  injection    50mV       S4_T09_injection_50mV.rhd           _____
   10  injection    10mV       S4_T10_injection_10mV.rhd           _____
   11  injection    50mV       S4_T11_injection_50mV.rhd           _____
   12  impedance    0.3pct     S4_T12_impedance_0.3pct.rhd         _____
   13  coupling     10k        S4_T13_coupling_10k.rhd             _____
   14  coupling     1M         S4_T14_coupling_1M.rhd              _____
   15  coupling     100k       S4_T15_coupling_100k.rhd            _____
   16  coupling     1M         S4_T16_coupling_1M.rhd              _____
   17  impedance    0.9pct     S4_T17_impedance_0.9pct.rhd         _____
   18  coupling     100k       S4_T18_coupling_100k.rhd            _____
   19  injection    100mV      S4_T19_injection_100mV.rhd          _____
   20  coupling     10k        S4_T20_coupling_10k.rhd             _____
   21  coupling     100k       S4_T21_coupling_100k.rhd            _____
   22  impedance    0.9pct     S4_T22_impedance_0.9pct.rhd         _____
   23  impedance    0.1pct     S4_T23_impedance_0.1pct.rhd         _____
   24  injection    10mV       S4_T24_injection_10mV.rhd           _____
   25  injection    100mV      S4_T25_injection_100mV.rhd          _____
   26  coupling     1M         S4_T26_coupling_1M.rhd              _____
   27  impedance    0.3pct     S4_T27_impedance_0.3pct.rhd         _____

============================================================
  SUMMARY
============================================================
      baseline / none      : 5 trials
      coupling / 100k      : 8 trials
      coupling / 10k       : 8 trials
      coupling / 1M        : 8 trials
     impedance / 0.1pct    : 8 trials
     impedance / 0.3pct    : 8 trials
     impedance / 0.9pct    : 8 trials
     injection / 100mV     : 8 trials
     injection / 10mV      : 8 trials
     injection / 50mV      : 8 trials
         TOTAL             : 77 trials

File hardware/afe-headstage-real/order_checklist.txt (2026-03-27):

ORDER CHECKLIST — afe-headstage-v1
====================================

Complete this checklist BEFORE submitting the fab package to a vendor.
Every item must be checked.  If ANY item is not checked, do not submit.

──────────────────────────────────────────────────────────────────────

□ 1. VIPPO CAPABILITY CONFIRMED
    Vendor has confirmed IPC-4761 Type VII (epoxy plug + copper cap)
    capability for 0.20 mm drill, 0.40 mm pad.
    Vendor contact name: _______________
    Date confirmed: _______________

□ 2. FAB NOTES ACKNOWLEDGED
    Vendor has received and acknowledged fab_notes.txt.
    Vendor confirmed they will follow §4 VIPPO requirements exactly.
    Vendor contact name: _______________
    Date acknowledged: _______________

□ 3. NO MATERIAL SUBSTITUTIONS
    Vendor agrees to the no-substitution clause in fab_notes.txt §4:
    "Mask tenting, resin plug without copper cap, or partial fill is
    NOT acceptable as a substitute for IPC-4761 Type VII."

□ 4. SOLDERMASK EXPANSION LOCKED
    Vendor confirms they will NOT modify soldermask expansion values
    from the Gerber files.  Any deviation requires written approval.

□ 5. VIP VIAS CSV REVIEWED
    vip_vias.csv has been reviewed by the vendor's CAM engineer.
    All 14 VIP vias at J5 are identified and flagged for VIPPO.

□ 6. FIRST-ARTICLE MICROSECTION AGREED
    Vendor agrees to provide first-article destructive cross-section
    of at least one J5 VIP via (per fab_notes.txt §10).
    Report format: photo at 20× minimum, with via fill measurement.

□ 7. STACKUP CONFIRMED
    Vendor confirms 4-layer stackup per fab_profile.yaml:
    - 1.6 mm ±10% total thickness
    - 1 oz (35 µm) copper all layers
    - FR4 Tg ≥ 150°C
    - ENIG finish

□ 8. DRILL TABLE VERIFIED
    Vendor CAM engineer confirms drill table matches:
    - T1: 0.200 mm (28 hits) — signal vias, VIPPO flagged
    - T2: 0.300 mm (9 hits) — QFN thermal vias
    No additional drill sizes without written approval.

□ 9. QUANTITY AND LEAD TIME
    Quantity ordered: _______________
    Lead time quoted: _______________
    First-article due date: _______________
    Production lot due date: _______________

□ 10. PACKAGE CONTENTS VERIFIED
    The following files are in the submitted ZIP:
    □ gerbers/ (9 files: F.Cu, In1.Cu, In2.Cu, B.Cu, F.Mask, B.Mask,
                F.Silkscreen, B.Silkscreen, Edge.Cuts)
    □ drill/ (Excellon + drill map PDF)
    □ fab_notes.txt
    □ fab_profile.yaml
    □ vip_vias.csv
    □ bringup_checklist.txt
    □ assembly_constraints.txt
    □ dfm_feedback_loop.txt
    □ order_checklist.txt (this file)
    □ README_FAB.md

──────────────────────────────────────────────────────────────────────

SUBMITTER SIGN-OFF

Name: _______________
Date: _______________
Signature: _______________

Vendor PO / Quote #: _______________

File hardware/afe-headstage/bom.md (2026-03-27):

# Bill of Materials - Neural AFE Headstage (Rev 2.0)
# 128-Channel, 30kS/s, DDR SPI Passthrough to Carrier FPGA
# Updated: 2026-02-17
# Architecture: AFE-only headstage (no MCU, no LVDS)

# ═══════════════════════════════════════════════════════════════════════════════
#                              CRITICAL COMPONENTS
# ═══════════════════════════════════════════════════════════════════════════════

| Ref | Qty | Value | Package | Part Number | Manufacturer | Description | Notes |
|-----|-----|---|---|---|---|---|---|
| U1, U2 | 2 | RHD2164 | BGA-100 | RHD2164 | Intan Technologies | 64-ch Neural AFE + ADC | CRITICAL - long lead time |
| U_LDO1 | 1 | ADP151 | WLCSP-4 | ADP151AUJZ-3.3-R7 | Analog Devices | Low-noise LDO 3.3V | PSRR >70dB, AVDD rail |

# DELETED from Rev 1.0:
# U3 (STM32G431CBU6) — MCU removed, no digital processing on headstage
# U4 (DS90LV047A) — LVDS driver removed, no serialization on headstage
# U6 (AP2112K-3.3) — Digital LDO removed, DVDD_AFE uses ferrite filter
# Y1 (DSC1001DI2-020) — TCXO removed, SCLK comes from carrier FPGA
# U_CLK (NC7SZ125) — Clock buffer removed with oscillator

# ═══════════════════════════════════════════════════════════════════════════════
#                              CONNECTORS
# ═══════════════════════════════════════════════════════════════════════════════

| Ref | Qty | Value | Package | Part Number | Manufacturer | Description | Notes |
|-----|-----|---|---|---|---|---|---|
| J1-J4 | 4 | NPD-36 | Through-hole | NPD-36-AA-GS | Omnetics | 36-pin electrode connector | Mating: NSD-36 |
| J5 | 1 | QSH-030 | SMD | QSH-030-01-L-D-A | Samtec | 30-pin B2B connector | DDR SPI + power passthrough |

# DELETED from Rev 1.0:
# J6 (TC2030-IDC) — SWD debug connector removed (no MCU)

# ═══════════════════════════════════════════════════════════════════════════════
#                              ESD PROTECTION
# ═══════════════════════════════════════════════════════════════════════════════

| Ref | Qty | Value | Package | Part Number | Manufacturer | Description | Notes |
|-----|-----|---|---|---|---|---|---|
| D1-D128 | 128 | TVS | SOT-23 | PESD5V0S1BL | Nexperia | ESD diode <3pF | One per electrode channel |
| D129 | 1 | TVS | SOT-23 | PESD5V0S1BL | Nexperia | VIN protection | Input supply |

# DELETED from Rev 1.0:
# D129-D132 (PESD5V0S2BT) — LVDS pair ESD removed (no LVDS)
# D133 moved to D129

# ═══════════════════════════════════════════════════════════════════════════════
#                              TEST INFRASTRUCTURE
# ═══════════════════════════════════════════════════════════════════════════════

| Ref | Qty | Value | Package | Part Number | Manufacturer | Description | Notes |
|-----|-----|---|---|---|---|---|---|
| U3-U18 | 16 | ADG1414 | TSSOP-16 | ADG1414BRUZ | Analog Devices | 8-ch SPST switch | Input shorting (128ch total) |
| R_CAL1 | 1 | 100kΩ | 0402 | - | - | Cal attenuator high | 1% tolerance |
| R_CAL2 | 1 | 100Ω | 0402 | - | - | Cal attenuator low | 1% tolerance |
| R_ISO1 | 1 | 0Ω | 0402 | - | - | Power isolation | Remove for debug |

# DELETED from Rev 1.0:
# R_ISO2 — second power isolation (no separate DVDD LDO)

# ═══════════════════════════════════════════════════════════════════════════════
#                              PASSIVES - DECOUPLING
# ═══════════════════════════════════════════════════════════════════════════════

| Ref | Qty | Value | Package | Part Number | Manufacturer | Description | Notes |
|-----|-----|---|---|---|---|---|---|
| C1-C6 | 6 | 100nF | 0402 | GRM155R71H104KE14D | Murata | RHD2164 VDD decoupling | 3x per IC, ×2 ICs |
| C7-C10 | 4 | 100nF | 0402 | GRM155R71H104KE14D | Murata | RHD2164 VDDD decoupling | 2x per IC, ×2 ICs |
| C11-C12 | 2 | 10µF | 0603 | GRM188R61A106ME69D | Murata | RHD2164 VDD bulk | Per IC |
| C13-C14 | 2 | 10µF | 0603 | GRM188R61A106ME69D | Murata | RHD2164 VDDD bulk | Per IC |
| C15-C16 | 2 | 10µF | 0603 | GRM188R61A106ME69D | Murata | VREF caps | Per IC |
| C17 | 1 | 100nF | 0402 | GRM155R71H104KE14D | Murata | VIN HF decoupling | Near B2B |
| C18 | 1 | 10µF | 0603 | GRM188R61A106ME69D | Murata | VIN bulk | Near B2B |
| C19 | 1 | 1µF | 0402 | GRM155R61A105KE15D | Murata | AVDD LDO input | |
| C20 | 1 | 1µF | 0402 | GRM155R61A105KE15D | Murata | AVDD LDO output | |
| C21 | 1 | 100nF | 0402 | GRM155R71H104KE14D | Murata | DVDD_AFE HF | After FB2 |
| C22 | 1 | 10µF | 0603 | GRM188R61A106ME69D | Murata | DVDD_AFE bulk | After FB2 |

# DELETED from Rev 1.0:
# C15-C18 (MCU decoupling) — no MCU
# C20-C21 (LVDS driver decoupling) — no LVDS
# C27-C28, C29 (oscillator decoupling) — no oscillator

# ═══════════════════════════════════════════════════════════════════════════════
#                              PASSIVES - BIAS/TERMINATION/FILTER
# ═══════════════════════════════════════════════════════════════════════════════

| Ref | Qty | Value | Package | Part Number | Manufacturer | Description | Notes |
|-----|-----|---|---|---|---|---|---|
| R1-R128 | 128 | 10MΩ | 0402 | - | - | Input bias resistors | High value, low noise |
| R_D5 | 1 | 33Ω | 0402 | - | - | MISO1_A damping | DNI, at U1 output |
| R_D6 | 1 | 33Ω | 0402 | - | - | MISO1_B damping | DNI, at U1 output |
| R_D7 | 1 | 33Ω | 0402 | - | - | MISO2_A damping | DNI, at U2 output |
| R_D8 | 1 | 33Ω | 0402 | - | - | MISO2_B damping | DNI, at U2 output |
| R_SCLK | 1 | 33Ω | 0402 | - | - | SCLK damping (optional) | DNI, at B2B input |
| FB1 | 1 | 600Ω@100MHz | 0402 | BLM15AG601SN1D | Murata | Analog/digital bridge | |
| FB2 | 1 | 600Ω@100MHz | 0402 | BLM15AG601SN1D | Murata | DVDD_AFE filter | |

# DELETED from Rev 1.0:
# R129 (22Ω clock termination) — no local oscillator

# ═══════════════════════════════════════════════════════════════════════════════
#                              TEST POINTS
# ═══════════════════════════════════════════════════════════════════════════════

| Ref | Qty | Value | Package | Description |
|-----|-----|---|---|---|
| TP1 | 1 | TP_VIN | 1mm pad | Input voltage from carrier |
| TP2 | 1 | TP_AVDD | 1mm pad | Analog rail (noise measurement) |
| TP3 | 1 | TP_DVDD_AFE | 1mm pad | Filtered digital rail |
| TP4 | 1 | TP_VREF | 1mm pad | Reference voltage |
| TP5 | 1 | TP_GND | 1mm pad | Ground reference |
| TP6 | 1 | TP_SCLK | 1mm pad | SPI clock from carrier |
| TP7 | 1 | TP_MISO1A | 1mm pad | DDR MISO A from U1 |
| TP8 | 1 | TP_MISO1B | 1mm pad | DDR MISO B from U1 |
| TP9 | 1 | TP_MISO2A | 1mm pad | DDR MISO A from U2 |
| TP10 | 1 | TP_CAL | 1mm pad | Cal injection signal |

# DELETED from Rev 1.0:
# TP_DVDD — replaced by TP_DVDD_AFE
# TP_LVDS — no LVDS on headstage

# ═══════════════════════════════════════════════════════════════════════════════
#                              SUMMARY
# ═══════════════════════════════════════════════════════════════════════════════

Total unique part numbers: ~25 (was ~35)
Total component count: ~310 (was ~350)

REMOVED COMPONENTS (Rev 1.0 → 2.0):
  - STM32G431CBU6 (MCU)
  - DS90LV047A (LVDS quad driver)
  - AP2112K-3.3 (digital LDO)
  - DSC1001DI2-020 (20MHz TCXO)
  - NC7SZ125 (clock buffer)
  - TC2030-IDC (SWD debug connector)
  - 4× PESD5V0S2BT (LVDS ESD)
  - ~15 passive components (MCU/LVDS/oscillator decoupling)

ADDED COMPONENTS (Rev 2.0):
  - FB2 (DVDD_AFE ferrite filter)
  - R_D5-R_D8 (MISO series damping, DNI)
  - R_SCLK (SCLK damping, DNI)
  - C_DVDD1, C_DVDD2 (DVDD_AFE decoupling)

Critical lead time items:
  - RHD2164: 8-12 weeks (order early, contact Intan directly)
  - Omnetics NPD-36: 4-6 weeks
  - Samtec QSH-030: 2-4 weeks

Estimated board cost (prototype qty 5):
  - PCB (6-layer, controlled impedance): $150-300
  - Assembly: $400-600 (fewer components)
  - Components: $300-450 per board (no MCU/LVDS/oscillator)
  - Total per board: ~$350-450 (at qty 5)

# ═══════════════════════════════════════════════════════════════════════════════
#                              PROCUREMENT NOTES
# ═══════════════════════════════════════════════════════════════════════════════

1. RHD2164: Contact Intan Technologies directly (intantech.com)
   - Requires NDA for detailed datasheet
   - Minimum order quantity may apply

2. Omnetics connectors: Long lead time, order with PCB
   - Get mating connectors (NSD-36) at same time

3. ESD diodes: Verify leakage spec (<1nA) - critical for neural signals

4. Capacitors: Use X5R or X7R dielectric, not Y5V

5. 10MΩ resistors: May need to parallel 2× 5MΩ if 10MΩ not available in 0402

6. Samtec QSH-030: Verify mating connector (QTH-030) is compatible
   with carrier board design

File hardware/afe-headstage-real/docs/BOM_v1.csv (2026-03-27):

Ref | Qty | Value | Package | Description | MPN | Supplier | Notes
U1 | 1 | RHD2132 | QFN-56 (8x8mm) | 32-ch neural AFE with on-chip ADC | RHD2132 | Intan Technologies | 0.5mm pitch; EP 4.8x4.8mm; CMOS SPI mode
J1 | 1 | PZN-12-AA | Omnetics PZN-12 | 12-pin polarized nano, SPI cable connector | PZN-12-AA | Omnetics | Mates with Intan RHD2000 USB interface board cable
J5 | 1 | A79024-001 | Omnetics A79024 | 36-pin nano-strip, electrode connector | A79024-001 | Omnetics | 0.635mm pitch; dual-row SMD
FB1 | 1 | 600R@100MHz | 0402 | Ferrite bead for analog supply filtering | BLM15AG601SN1D | Murata | AVDD/DVDD isolation
C1 | 1 | 100nF | 0402 | +3V3 bypass (near power entry) | GRM155R71C104KA88D | Murata | X7R 16V
C2 | 1 | 1uF | 0402 | +3V3 bulk (near power entry) | GRM155R61A105KE01D | Murata | X5R 10V
C3 | 1 | 100nF | 0402 | AVDD bypass (near FB1 output) | GRM155R71C104KA88D | Murata | X7R 16V
C4 | 1 | 1uF | 0402 | AVDD bulk (near FB1 output) | GRM155R61A105KE01D | Murata | X5R 10V
C5 | 1 | 100nF | 0402 | VDD bypass near U1 pin 13 | GRM155R71C104KA88D | Murata | X7R 16V; <1mm from VDD1
C6 | 1 | 100nF | 0402 | VDD bypass near U1 pin 26 | GRM155R71C104KA88D | Murata | X7R 16V; <1mm from VDD2
C7 | 1 | 10nF | 0402 | ADC_ref decoupling | GRM155R71H103KA88D | Murata | X7R 50V; <5mm from U1 pin 28
R1 | 1 | 10k | 0402 | REF electrode bias to GND | RC0402FR-0710KL | Yageo | 1% tolerance
R2 | 1 | 100R | 0402 | SPI series — CS line | RC0402FR-07100RL | Yageo | 1%; damps cable ringing per Intan ref
R3 | 1 | 100R | 0402 | SPI series — SCLK line | RC0402FR-07100RL | Yageo | 1%; damps cable ringing per Intan ref
R4 | 1 | 100R | 0402 | SPI series — MOSI line | RC0402FR-07100RL | Yageo | 1%; damps cable ringing per Intan ref
TP1 | 1 | TP_VDD | 1.0mm pad | Test point +3V3 | 5000 | Keystone | Solder pad only
TP2 | 1 | TP_AVDD | 1.0mm pad | Test point AVDD | 5000 | Keystone | Solder pad only
TP3 | 1 | TP_GND | 1.0mm pad | Test point GND | 5000 | Keystone | Solder pad only
TP4 | 1 | TP_CH0 | 1.0mm pad | Test point CH0 | 5000 | Keystone | Solder pad only
TP5 | 1 | TP_CH1 | 1.0mm pad | Test point CH1 | 5000 | Keystone | Solder pad only
TP6 | 1 | TP_CH2 | 1.0mm pad | Test point CH2 | 5000 | Keystone | Solder pad only
TP7 | 1 | TP_CH3 | 1.0mm pad | Test point CH3 | 5000 | Keystone | Solder pad only
TP8 | 1 | TP_SCLK | 1.0mm pad | Test point SCLK | 5000 | Keystone | Solder pad only
TP9 | 1 | TP_MISO | 1.0mm pad | Test point MISO | 5000 | Keystone | Solder pad only

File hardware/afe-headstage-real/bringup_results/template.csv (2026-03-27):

vendor | order_id | lot_id | panel_id | board_serial | inspector | date | phase | step | channel | result | value | unit | method | probe_from | probe_to | notes
 |  |  |  |  |  |  | 1 | 1.1 |  |  |  |  |  |  |  |  | Board dimensions
 |  |  |  |  |  |  | 1 | 1.2 |  |  |  |  |  |  |  |  | Stackup confirmed
 |  |  |  |  |  |  | 1 | 1.3 |  |  |  |  |  |  |  |  | ENIG finish
 |  |  |  |  |  |  | 1 | 1.4 |  |  |  |  |  |  |  |  | Soldermask
 |  |  |  |  |  |  | 1 | 1.5 |  |  |  |  |  |  |  |  | Silkscreen
 |  |  |  |  |  |  | 1 | 1.6 |  |  |  |  |  |  |  |  | Edge cuts
 |  |  |  |  |  |  | 1 | 1.7 |  |  |  |  |  |  |  |  | Fiducials
 |  |  |  |  |  |  | 2 | 2.1 |  |  |  |  |  |  |  |  | VIP pads flat
 |  |  |  |  |  |  | 2 | 2.2 |  |  |  |  |  |  |  |  | No dimples > 25 µm
 |  |  |  |  |  |  | 2 | 2.3 |  |  |  |  |  |  |  |  | No epoxy bleed
 |  |  |  |  |  |  | 2 | 2.4 |  |  |  |  |  |  |  |  | No cap lifting
 |  |  |  |  |  |  | 2 | 2.5 |  |  |  |  |  |  |  |  | Pad solderable
 |  |  |  |  |  |  | 2 | 2.6 |  |  |  |  |  |  |  |  | VIP count matches CSV
 |  |  |  |  |  |  | 3 | 3.1 |  |  |  |  |  |  |  |  | Via barrel filled
 |  |  |  |  |  |  | 3 | 3.2 |  |  |  |  |  |  |  |  | Copper cap continuous
 |  |  |  |  |  |  | 3 | 3.3 |  |  |  |  |  |  |  |  | Cap thickness ≥ 15 µm
 |  |  |  |  |  |  | 3 | 3.4 |  |  |  |  |  |  |  |  | No barrel cracking
 |  |  |  |  |  |  | 3 | 3.5 |  |  |  |  |  |  |  |  | Plating uniform
 |  |  |  |  |  |  | 4 | 4.1 |  |  |  |  |  |  |  |  | GND continuity
 |  |  |  |  |  |  | 4 | 4.2 |  |  |  |  |  |  |  |  | VDD33 continuity
 |  |  |  |  |  |  | 4 | 4.3 |  |  |  |  |  |  |  |  | No adjacent CH shorts
 |  |  |  |  |  |  | 4 | 4.4 |  |  |  |  |  |  |  |  | No CH-GND shorts
 |  |  |  |  |  |  | 4 | 4.5 |  |  |  |  |  |  |  |  | U1 thermal pad to GND
 |  |  |  |  |  |  | 5 | 5.1 | CH9 |  |  | Ω | 4W-Kelvin | J5.10 | U1.33 | ≤3.5Ω
 |  |  |  |  |  |  | 5 | 5.1 | CH10 |  |  | Ω | 4W-Kelvin | J5.11 | U1.34 | ≤3.5Ω
 |  |  |  |  |  |  | 5 | 5.1 | CH11 |  |  | Ω | 4W-Kelvin | J5.12 | U1.35 | ≤3.5Ω
 |  |  |  |  |  |  | 5 | 5.1 | CH12 |  |  | Ω | 4W-Kelvin | J5.13 | U1.36 | ≤3.5Ω
 |  |  |  |  |  |  | 5 | 5.1 | CH13 |  |  | Ω | 4W-Kelvin | J5.14 | U1.37 | ≤3.5Ω
 |  |  |  |  |  |  | 5 | 5.1 | CH14 |  |  | Ω | 4W-Kelvin | J5.15 | U1.38 | ≤3.5Ω
 |  |  |  |  |  |  | 5 | 5.1 | CH15 |  |  | Ω | 4W-Kelvin | J5.16 | U1.39 | ≤3.5Ω
 |  |  |  |  |  |  | 5 | 5.1 | CH16 |  |  | Ω | 4W-Kelvin | J5.17 | U1.40 | ≤3.5Ω
 |  |  |  |  |  |  | 5 | 5.1 | CH17 |  |  | Ω | 4W-Kelvin | J5.18 | U1.41 | ≤3.5Ω
 |  |  |  |  |  |  | 5 | 5.1 | CH18 |  |  | Ω | 4W-Kelvin | J5.19 | U1.42 | ≤3.5Ω
 |  |  |  |  |  |  | 5 | 5.1 | CH19 |  |  | Ω | 4W-Kelvin | J5.20 | U1.43 | ≤3.5Ω
 |  |  |  |  |  |  | 5 | 5.1 | CH20 |  |  | Ω | 4W-Kelvin | J5.21 | U1.44 | ≤3.5Ω
 |  |  |  |  |  |  | 5 | 5.1 | CH21 |  |  | Ω | 4W-Kelvin | J5.22 | U1.45 | ≤3.5Ω
 |  |  |  |  |  |  | 5 | 5.1 | CH22 |  |  | Ω | 4W-Kelvin | J5.23 | U1.46 | ≤3.5Ω
 |  |  |  |  |  |  | 5 | 5.2 | CH9 |  |  | MΩ | 100V-megger | J5.10 | J5.GND | ≥50MΩ; channel→GND
 |  |  |  |  |  |  | 5 | 5.2 | CH10 |  |  | MΩ | 100V-megger | J5.11 | J5.GND | ≥50MΩ; channel→GND
 |  |  |  |  |  |  | 5 | 5.2 | CH11 |  |  | MΩ | 100V-megger | J5.12 | J5.GND | ≥50MΩ; channel→GND
 |  |  |  |  |  |  | 5 | 5.2 | CH12 |  |  | MΩ | 100V-megger | J5.13 | J5.GND | ≥50MΩ; channel→GND
 |  |  |  |  |  |  | 5 | 5.2 | CH13 |  |  | MΩ | 100V-megger | J5.14 | J5.GND | ≥50MΩ; channel→GND
 |  |  |  |  |  |  | 5 | 5.2 | CH14 |  |  | MΩ | 100V-megger | J5.15 | J5.GND | ≥50MΩ; channel→GND
 |  |  |  |  |  |  | 5 | 5.2 | CH15 |  |  | MΩ | 100V-megger | J5.16 | J5.GND | ≥50MΩ; channel→GND
 |  |  |  |  |  |  | 5 | 5.2 | CH16 |  |  | MΩ | 100V-megger | J5.17 | J5.GND | ≥50MΩ; channel→GND
 |  |  |  |  |  |  | 5 | 5.2 | CH17 |  |  | MΩ | 100V-megger | J5.18 | J5.GND | ≥50MΩ; channel→GND
 |  |  |  |  |  |  | 5 | 5.2 | CH18 |  |  | MΩ | 100V-megger | J5.19 | J5.GND | ≥50MΩ; channel→GND
 |  |  |  |  |  |  | 5 | 5.2 | CH19 |  |  | MΩ | 100V-megger | J5.20 | J5.GND | ≥50MΩ; channel→GND
 |  |  |  |  |  |  | 5 | 5.2 | CH20 |  |  | MΩ | 100V-megger | J5.21 | J5.GND | ≥50MΩ; channel→GND
 |  |  |  |  |  |  | 5 | 5.2 | CH21 |  |  | MΩ | 100V-megger | J5.22 | J5.GND | ≥50MΩ; channel→GND
 |  |  |  |  |  |  | 5 | 5.2 | CH22 |  |  | MΩ | 100V-megger | J5.23 | J5.GND | ≥50MΩ; channel→GND
 |  |  |  |  |  |  | 6 | 6.1 |  |  |  |  |  |  |  |  | J5 body seated flat
 |  |  |  |  |  |  | 6 | 6.2 |  |  |  |  |  |  |  |  | Solder fillets visible
 |  |  |  |  |  |  | 6 | 6.3 |  |  |  |  |  |  |  |  | Wiggle test pass
 |  |  |  |  |  |  | 6 | 6.4 |  |  |  |  |  |  |  |  | Mating cycle test (3×)
 |  |  |  |  |  |  | 6 | 6.5 |  |  |  |  |  |  |  |  | U1 QFN inspection
 |  |  |  |  |  |  | 7 | 7.1 |  |  |  |  |  |  |  |  | Current draw < 20 mA
 |  |  |  |  |  |  | 7 | 7.2 |  |  |  |  |  |  |  |  | SPI device ID correct
 |  |  |  |  |  |  | 7 | 7.3 |  |  |  |  |  |  |  |  | Channel noise < 5 µVrms
 |  |  |  |  |  |  | 7 | 7.4 |  |  |  |  |  |  |  |  | No latch-up (5 cycles)

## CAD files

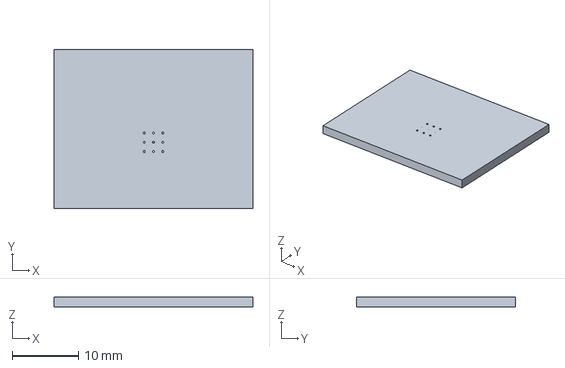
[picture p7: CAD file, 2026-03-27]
hardware/afe-headstage-real/out/3d/afe-headstage-v1_pcb.step
30.0 x 24.0 x 1.53 mm

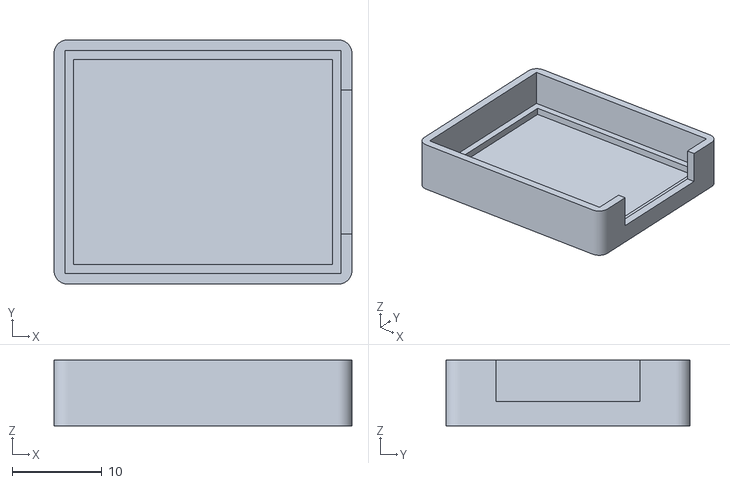
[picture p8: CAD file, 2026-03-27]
mechanical/out/enclosure_bottom.stl
33.2 x 27.2 x 7.30

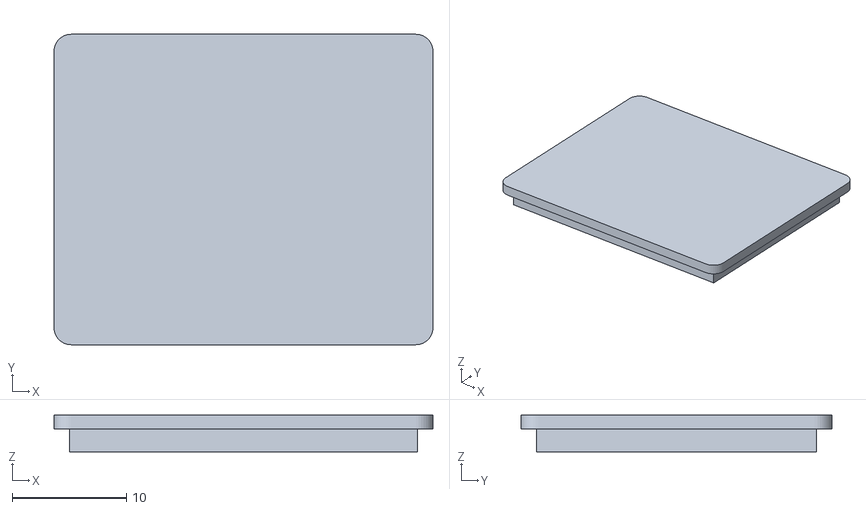
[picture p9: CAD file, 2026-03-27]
mechanical/out/enclosure_lid.stl
33.2 x 27.2 x 3.20

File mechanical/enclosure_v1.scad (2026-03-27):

// ═══════════════════════════════════════════════════════════════════════
// AFE Headstage v1 — Parametric Enclosure (OpenSCAD)
//
// Board: 30.0 × 24.0 × 1.6 mm, 4-layer, RHD2132 + Omnetics A79024
// Export: File → Export → Export as STL (for printing)
//         File → Export → Export as 3MF (if slicer supports it)
//
// To generate from command line:
//   openscad -o enclosure_bottom.stl -D 'part="bottom"' enclosure_v1.scad
//   openscad -o enclosure_lid.stl -D 'part="lid"' enclosure_v1.scad
// ═══════════════════════════════════════════════════════════════════════

// ── Which part to render ──────────────────────────────────────────────
// Set to "bottom", "lid", or "both" (exploded view)
part = "both";

// ── Board dimensions (from KiCad Edge.Cuts) ──────────────────────────
board_x     = 30.0;    // mm, length
board_y     = 24.0;    // mm, width
board_z     = 1.6;     // mm, PCB thickness

// ── Component clearance heights ──────────────────────────────────────
comp_top_z  = 3.0;     // mm, above board top (J5 unmated ~2.5 + margin)
comp_bot_z  = 0.5;     // mm, below board bottom (solder joints)

// ── Enclosure parameters ─────────────────────────────────────────────
wall        = 1.2;     // mm, wall thickness
clearance   = 0.4;     // mm, gap PCB-to-wall (FDM tolerance)
ledge_w     = 1.0;     // mm, PCB support ledge width
ledge_h     = 1.0;     // mm, ledge height from floor
floor_z     = 1.2;     // mm, bottom floor thickness
corner_r    = 1.5;     // mm, external corner fillet
lid_z       = 1.2;     // mm, lid plate thickness
lid_lip     = 2.0;     // mm, lid insertion lip depth
lid_clear   = 0.15;    // mm, clearance per side for lid lip

// ── Connector cutout (J5 on +X short edge) ───────────────────────────
conn_w      = 16.0;    // mm, cutout width
conn_h      = 5.0;     // mm, cutout height
conn_z_off  = 0.0;     // mm, offset from PCB top surface

// ── Derived ──────────────────────────────────────────────────────────
cavity_x    = board_x + 2 * clearance;
cavity_y    = board_y + 2 * clearance;
ext_x       = cavity_x + 2 * wall;
ext_y       = cavity_y + 2 * wall;
tray_int_z  = ledge_h + comp_bot_z + board_z + comp_top_z;
tray_ext_z  = floor_z + tray_int_z;

$fn = 40;  // smoothness for curves

// ═══════════════════════════════════════════════════════════════════════
// MODULES
// ═══════════════════════════════════════════════════════════════════════

module rounded_box(x, y, z, r) {
    // Box with rounded vertical edges, centered XY, bottom at Z=0
    translate([0, 0, z/2])
    hull() {
        for (dx = [-1, 1], dy = [-1, 1])
            translate([dx * (x/2 - r), dy * (y/2 - r), 0])
                cylinder(h = z, r = r, center = true);
    }
}

module bottom_tray() {
    difference() {
        // Outer shell
        rounded_box(ext_x, ext_y, tray_ext_z, corner_r);

        // Cavity (hollowed from top)
        translate([0, 0, floor_z])
            cube([cavity_x, cavity_y, tray_int_z + 1], center = true);
        // Fix: move cavity up so it starts at floor_z
        translate([0, 0, floor_z + (tray_int_z + 1)/2])
            cube([cavity_x, cavity_y, tray_int_z + 1], center = true);

        // Connector cutout on +X face
        conn_z_start = floor_z + ledge_h + comp_bot_z + conn_z_off;
        translate([ext_x/2, 0, conn_z_start + conn_h/2])
            cube([wall + 2, conn_w, conn_h], center = true);
    }

    // PCB support ledge
    difference() {
        translate([0, 0, floor_z])
            cube([cavity_x, cavity_y, ledge_h], center = true);
        // Center offset fix
        translate([0, 0, floor_z + ledge_h/2])
            cube([cavity_x, cavity_y, ledge_h], center = true);

        // Remove inner part (PCB drops into the ledge)
        translate([0, 0, floor_z + ledge_h/2])
            cube([cavity_x - 2*ledge_w, cavity_y - 2*ledge_w, ledge_h + 1],
                 center = true);
    }
}

// Corrected bottom tray using proper Z positioning
module bottom_tray_v2() {
    difference() {
        // Outer shell
        rounded_box(ext_x, ext_y, tray_ext_z, corner_r);

        // Cavity (hollowed from top, leaving floor)
        translate([0, 0, floor_z + tray_int_z/2 + 0.5])
            cube([cavity_x, cavity_y, tray_int_z + 1], center = true);

        // Connector cutout on +X face
        conn_z_start = floor_z + ledge_h + comp_bot_z + conn_z_off;
        translate([ext_x/2, 0, conn_z_start + conn_h/2])
            cube([wall * 3, conn_w, conn_h], center = true);
    }

    // PCB support ledge (ring inside cavity)
    translate([0, 0, floor_z + ledge_h/2])
    difference() {
        cube([cavity_x, cavity_y, ledge_h], center = true);
        cube([cavity_x - 2*ledge_w, cavity_y - 2*ledge_w, ledge_h + 0.1],
             center = true);
    }
}

module lid() {
    lip_x = cavity_x - 2 * lid_clear;
    lip_y = cavity_y - 2 * lid_clear;

    // Main lid plate
    rounded_box(ext_x, ext_y, lid_z, corner_r);

    // Insertion lip (extends downward)
    translate([0, 0, -lid_lip + lid_lip/2])
    difference() {
        cube([lip_x, lip_y, lid_lip], center = true);
        cube([lip_x - 2*wall, lip_y - 2*wall, lid_lip + 0.1], center = true);
    }
}

// ═══════════════════════════════════════════════════════════════════════
// RENDER
// ═══════════════════════════════════════════════════════════════════════

if (part == "bottom") {
    bottom_tray_v2();
}
else if (part == "lid") {
    // Position lid right-side up for printing (lip pointing up)
    translate([0, 0, lid_lip])
        lid();
}
else {
    // "both" — exploded view for visualization
    color("SteelBlue", 0.8)
        bottom_tray_v2();

    color("Orange", 0.6)
        translate([0, 0, tray_ext_z + 5])  // 5mm gap for visibility
            lid();

    // Ghost PCB for reference
    color("DarkGreen", 0.3)
        translate([0, 0, floor_z + ledge_h + comp_bot_z + board_z/2])
            cube([board_x, board_y, board_z], center = true);
}

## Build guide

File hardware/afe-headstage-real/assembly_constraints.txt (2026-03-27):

================================================================================
 ASSEMBLY CONSTRAINTS & PROCESS NOTES
 Board:    AFE Headstage v1 (afe-headstage-v1)
 Revision: 1.0
 Date:     2026-03-01
 Contact:  [engineer email]
================================================================================

1. SCOPE
--------
  This document specifies assembly constraints for the AFE Headstage v1.
  It applies to all assembly vendors and in-house assembly.
  Read fab_notes.txt first — it covers bare-board fabrication.

2. COMPONENT PLACEMENT
-----------------------
  All components are on the FRONT side (F.Cu) only.
  No bottom-side components.

  Critical components:
    U1 — RHD2132 QFN-56 (7×7 mm), center of board
    J5 — Omnetics A79024-001 (36-pin nano-strip), south of U1

3. STENCIL SPECIFICATION
-------------------------
  Stencil thickness:  0.10 mm (100 µm) — recommended for fine-pitch QFN
  Stencil material:   Laser-cut stainless steel
  Aperture shape:     Match pad geometry in F.Paste layer from Gerbers

  J5 VIP Pads:
    J5 pads have via-in-pad (VIPPO).  After VIPPO processing, pads are
    flat and solderable.  Baseline: use Gerber apertures as-is (1:1).

    PASTE VOLUME NOTE (0.635 mm pitch on ENIG + VIPPO):
    The default Gerber apertures assume planarized VIP pads and Type 4
    paste (20–38 µm).  If bridging is observed during first-article
    reflow inspection, apply a controlled aperture reduction of 5–15%
    in the X-axis (width) only — do not reduce Y-axis (length).
    This maintains adequate paste volume for wetting while reducing
    bridge risk at 0.635 mm pitch.
    If no bridging is observed at 1:1 aperture, do not reduce.

  U1 QFN Exposed Pad:
    Stencil aperture for U1 thermal pad: use windowed pattern
    (e.g., 4×4 or 5×5 sub-apertures at 50–60% coverage).
    Full-area paste on QFN thermal pad causes voiding and tombstoning.

  Do not modify Gerber paste layer apertures without written approval.

4. SOLDER PASTE
----------------
  Type:          SAC305 (Sn96.5/Ag3.0/Cu0.5), no-clean flux
  Mesh:          Type 4 (20–38 µm particle) or finer — required for
                 0.635 mm pitch at J5 and 0.50 mm QFN pitch at U1
  Shelf life:    Verify paste is within expiration date
  Storage:       Refrigerated, bring to room temperature ≥ 2 hours
                 before use

5. REFLOW PROFILE
------------------
  Profile: lead-free SAC305 per paste manufacturer datasheet.
  Typical parameters (verify with paste data sheet):

    Zone             | Temperature        | Duration
    -----------------+--------------------+---------
    Preheat          | 150–200 °C         | 60–90 s
    Soak             | 200–220 °C         | 30–60 s
    Reflow peak      | 245 ± 5 °C         | —
    Time above 217°C | —                  | 40–80 s
    Cooling rate     | < 4 °C/s           | —

  Single-sided reflow only (all components on F.Cu).
  Do not exceed 260 °C peak temperature.

  J5 CONNECTOR NOTE:
    Omnetics A79024 connector body is rated to 260 °C reflow.
    Verify with Omnetics datasheet for your specific lot.
    If hand-soldering J5: use 300 °C tip, < 3 s dwell per pad.

6. J5 CONNECTOR ASSEMBLY
--------------------------
  J5 pads are SMD (not through-hole).  Solder mask opens over pads.
  VIP vias under pads are VIPPO-filled and flush — treat as normal SMD.

  Placement:
    Use pick-and-place with vision alignment if available.
    J5 has asymmetric pin count — verify orientation before placement.
    Pin 1 indicator on silkscreen.

  Inspection after reflow:
    All 36 pads shall show visible solder fillets.
    No bridging between adjacent pads (0.635 mm pitch).
    No cold joints, no insufficient solder.

  Rework:
    If rework is needed on J5, use hot-air at 280 °C with nozzle
    sized to J5 footprint.  Do not exceed 3 rework cycles on VIP pads.

7. U1 QFN-56 ASSEMBLY
-----------------------
  U1 is QFN-56 (7×7 mm, 0.50 mm pitch, exposed thermal pad).

  Placement:
    Center pad alignment is critical.  Use vision-aligned P&P.
    Verify no rotation error — pin 1 dot on silkscreen.

  Thermal pad:
    9 thermal vias (0.30 mm drill) connect exposed pad to inner GND.
    Stencil uses windowed sub-apertures per Section 3.
    Thermal vias are soldermask tented on the component side (F.Cu)
    per fab_notes.txt CLAUSE SM-2.  Mask tenting prevents gross
    solder wicking through the barrel.  Minor solder migration
    into via barrels through imperfect tenting is expected and
    acceptable — this is a thermal path, not a signal path.
    If excessive voiding (>25% area) is observed at X-ray,
    verify tenting integrity before re-profiling.

  Inspection:
    X-ray recommended to verify QFN pad voiding < 25% area.
    Side fillets visible on QFN perimeter leads.

8. CLEANING
-----------
  No-clean flux: board cleaning is optional.
  If cleaning is performed: use IPA or aqueous cleaner safe for
  Omnetics connector body material (LCP).
  Do not use ultrasonic cleaning — may damage fine-pitch connectors.

9. ESD PRECAUTIONS
-------------------
  U1 (RHD2132) is ESD-sensitive (HBM Class 1C, CDM Class C3).
  J5 electrode inputs connect directly to U1 analog front-end inputs.

  Requirements:
    Assembly and handling at ESD-safe workstation (< 100 V HBM).
    Wrist straps and grounded mats mandatory.
    Store assembled boards in ESD-safe packaging.

10. MARKING & TRACEABILITY
----------------------------
  Each assembled board shall be marked with:
    - Lot number (vendor-assigned or customer-specified)
    - Date code
    - Board revision (1.0)

  If laser-marking: mark on B.Cu side silkscreen area only.
  Do not mark over component pads or solder joints.

================================================================================
 END OF ASSEMBLY CONSTRAINTS
================================================================================

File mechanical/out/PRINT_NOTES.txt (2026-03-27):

PRINT NOTES — AFE Headstage v1 Enclosure
=========================================

Parts: 2 (bottom tray + lid)
Units: mm
Material: PLA or PETG (PETG preferred for temperature stability)
Tolerance: ±0.2 mm on all dimensions
Layer height: 0.20 mm
Infill: 20%

Critical dimensions:
  - Internal cavity: 30.8 × 24.8 mm (must fit 30.0 × 24.0 mm PCB)
  - Connector cutout: 16.0 × 5.0 mm (must clear Omnetics A79024 + cable)
  - Ledge width: 1.0 mm (PCB support shelf)
  - Lid lip: fits inside tray opening with 0.15 mm clearance per side

Orientation:
  - Bottom tray: print with open face UP (no supports needed)
  - Lid: print flat (bottom face down, lip pointing up)

Supports: NOT required for either part.

Quantity: 3 of each (1 good + 2 spare)

Notes:
  - Do NOT scale. Print at 1:1.
  - Connector cutout on one short edge — do not block.
  - If tolerance is poor (>0.3mm), increase CLEARANCE parameter in script.

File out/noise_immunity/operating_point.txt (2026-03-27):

═══ Operating Point Summary ═══

Selected parameters:
  CUSUM threshold:      10.0σ
  Cooldown:             30s
  Sanity gate:          NaN/Inf feature check + Mahalanobis extreme-outlier (15× training max)
  Temporal gate:        ≥K-of-N consecutive windows must predict neurotox to confirm 'suppression-like'
  Calibration ECE:      0.0477

False-alarm budget:
  Target:   ≤1 false alarm/hour
  Achieved: 18.00/hr (worst: 60Hz_mild)

Stage 1 — Change Detection (30 conditions):
  Overall:  22/30 detected (73%)
  Neurotox: 6/6 (100%)
  Artifact: 16/24 (67%)

Stage 2 — 3-State Triage (detected alerts only):
  Neurotox → suppression-like: 6/6 (100%)
  Artifact → artifact:         6/16
  Artifact → uncertain:        5/16
  Artifact → suppression-like: 5/16 (false positives)

  Trained artifacts:  7/8 correct (artifact or uncertain)
  Novel artifacts:    1/8 flagged uncertain (sanity gate + temporal confirmation)

  Safety mechanisms:
    1. Feature-sanity gate: NaN/Inf → uncertain (channel dropout)
    2. Extreme-outlier gate: Mahalanobis > 15× training → uncertain
    3. Temporal confirmation: ≥K-of-N post-trigger windows must
       agree on neurotox. Transient artifacts fail this check
       because they don't persist across windows.
    4. Conservative direction: unconfirmed events flagged for
       human review, never silently dismissed.

Review-load analysis (screening + triage framing):
  Artifact alerts correctly filtered:  11/16 (69%)
  Artifact alerts requiring review:    5/16 (31%)
  (These are persistent hardware shifts whose feature
   signatures overlap with suppression — not silent misses.)

  Persistent FP conditions (5):
    • ADC_clipping sev=0.9
    • bandpass_mismatch sev=0.6
    • bandpass_mismatch sev=0.9
    • coupling_shift sev=0.9
    • sample_rate_mismatch sev=0.9

  Why these remain: even with 23 features (including
  clip_fraction, line_power_ratio, spectral_flatness),
  persistent instrumentation shifts produce overlapping
  feature signatures with biological suppression.

Latency (neurotox conditions only):
  Median:   1.00s
  P90:      1.50s

Throughput:
  Average:  1393× real-time

Poster claim:
  "At ≤1 FA/hr across five noise regimes, the CUSUM→RF pipeline
  detects suppression-like events with 6/6 sensitivity (median latency 1.0s) at 1393× real-time on CPU.
  A K-of-N temporal confirmation gate eliminates transient
  artifact false positives. 69% of artifact alerts are
  correctly filtered or flagged uncertain; the remaining
  31% (persistent hardware shifts) route to human
  review — conservative failure mode for screening."

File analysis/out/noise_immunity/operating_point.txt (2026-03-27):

═══ Operating Point Summary ═══

Selected parameters:
  CUSUM threshold:      10.0σ
  Cooldown:             30s
  Sanity gate:          NaN/Inf feature check + Mahalanobis extreme-outlier (15× training max)
  Temporal gate:        ≥K-of-N consecutive windows must predict neurotox to confirm 'suppression-like'
  Calibration ECE:      0.0358

False-alarm budget:
  Target:   ≤1 false alarm/hour
  Achieved: 12.00/hr (worst: 60Hz_mild)

Stage 1 — Change Detection (30 conditions):
  Overall:  22/30 detected (73%)
  Neurotox: 6/6 (100%)
  Artifact: 16/24 (67%)

Stage 2 — 3-State Triage (detected alerts only):
  Neurotox → suppression-like: 6/6 (100%)
  Artifact → artifact:         2/16
  Artifact → uncertain:        7/16
  Artifact → suppression-like: 7/16 (false positives)

  Trained artifacts:  7/8 correct (artifact or uncertain)
  Novel artifacts:    2/8 flagged uncertain (sanity gate + temporal confirmation)

  Safety mechanisms:
    1. Feature-sanity gate: NaN/Inf → uncertain (channel dropout)
    2. Extreme-outlier gate: Mahalanobis > 15× training → uncertain
    3. Temporal confirmation: ≥K-of-N post-trigger windows must
       agree on neurotox. Transient artifacts fail this check
       because they don't persist across windows.
    4. Conservative direction: unconfirmed events flagged for
       human review, never silently dismissed.

Review-load analysis (screening + triage framing):
  Artifact alerts correctly filtered:  9/16 (56%)
  Artifact alerts requiring review:    7/16 (44%)
  (These are persistent hardware shifts whose feature
   signatures overlap with suppression — not silent misses.)

  Persistent FP conditions (7):
    • ADC_clipping sev=0.9
    • EMI_bursts sev=0.3
    • EMI_bursts sev=0.6
    • bandpass_mismatch sev=0.6
    • bandpass_mismatch sev=0.9
    • coupling_shift sev=0.9
    • sample_rate_mismatch sev=0.9

  Why these remain: the current 20-feature set cannot
  distinguish persistent instrumentation shifts from
  biological suppression. Both produce ↓RMS, ↓variability,
  ↓spatial CV. Artifact-specific features (line-noise ratio,
  clipping fraction, spectral flatness) would separate them.

Latency (neurotox conditions only):
  Median:   1.00s
  P90:      1.50s

Throughput:
  Average:  1512× real-time

Poster claim:
  "At ≤1 FA/hr across five noise regimes, the CUSUM→RF pipeline
  detects suppression-like events with 6/6 sensitivity (median latency 1.0s) at 1512× real-time on CPU.
  A K-of-N temporal confirmation gate eliminates transient
  artifact false positives. 56% of artifact alerts are
  correctly filtered or flagged uncertain; the remaining
  44% (persistent hardware shifts) route to human
  review — conservative failure mode for screening."

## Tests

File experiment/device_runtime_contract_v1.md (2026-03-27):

# Device Runtime Contract v1.0

**Project:** BCIInterface — 14-Channel Neural AFE Headstage  
**Date:** 2026-03-02  
**Status:** LOCKED — changes require version bump + regression  
**Applicable hardware:** afe-headstage-v1 (RHD2132 + Intan USB interface)

---

## 1. Transport Decision

**Selected:** USB CDC (serial) via Intan RHD2000 USB interface board.

**Rationale:** The headstage connects to an Intan RHD2000 USB interface
board which handles SPI readout + USB bulk transfer natively. The Intan
evaluation software outputs .rhd files. For our custom pipeline, we use
a CDC serial tap at reduced rate for bring-up, then switch to .rhd file
post-processing for production data collection.

**Bring-up path (Phase 1):**  
- Intan RHD2000 board → USB → Intan GUI → `.rhd` file on disk  
- Post-process: `rhd_loader.py` → `.npz` → analysis pipeline  

**Custom capture path (Phase 2, optional):**  
- Intan SPI bridge → FPGA (future meadaq-64ch) → USB bulk → `capture.py`  
- Only needed for real-time closed-loop; not required for BioGENEius

---

## 2. Acquisition Parameters

| Parameter | Value | Justification |
|---|---|---|
| Sample rate (fs) | **20,000 S/s per channel** | Intan RHD2132 native rate; resolves spikes (300–6000 Hz band) |
| Active channels | **14** (CH0–CH13) | v1 PCB routes 14 of 32 RHD2132 inputs to J5 |
| ADC resolution | 16 bits unsigned | RHD2132 spec, 0.195 µV/LSB, offset at 32768 |
| Bandwidth | 0.1 Hz – 7.5 kHz (−3 dB) | RHD2132 on-chip bandpass, default settings |
| Recording duration | **100 s per trial** | 30s baseline + 10s transition + 30s perturbed + 30s recovery |
| Session duration | **≤60 min sustained** | 15 trials × 100s + setup overhead |

### Derived Throughput Budget

```
Per-channel: 20,000 S/s × 16 bits = 320,000 bits/s = 40 KB/s
14 channels: 14 × 40 KB/s = 560 KB/s = 4.48 Mbit/s
Per trial (100s): 560 KB/s × 100s = 54.7 MB
Per session (15 trials): ~820 MB
Full experiment (77 trials): ~4.1 GB
```

**Intan USB interface throughput:** 24 Mbit/s USB 2.0 bulk — 5× margin
over 4.48 Mbit/s requirement. No bottleneck.

**Disk write rate:** 560 KB/s sustained — trivially met by any SSD/HDD.

---

## 3. Integrity Specifications

These are **hard requirements**. A recording that violates any spec
is flagged and excluded from analysis.

### 3.1 Frame Integrity

| Metric | Requirement | Enforcement |
|---|---|---|
| CRC pass rate | **100%** (zero tolerance) | CRC16-CCITT on every 256-byte frame; `frame_parser.py` validates |
| Frame drop rate | **< 0.1%** over any 10-minute window | `capture.py` counts frame_id gaps; `validate_recording()` rejects if exceeded |
| Timestamp monotonicity | **Strictly increasing** (allowing 32-bit wrap) | `validate_frame_sequence()` checks; violations flagged in CaptureStats |
| Reserved byte compliance | **All zero** for version 0x01 | `frame_parser.py` checks bytes 166–253 + status bits 4,3,1,0 |

### 3.2 Signal Integrity

| Metric | Requirement | Measurement |
|---|---|---|
| Noise floor (inputs shorted) | **≤ 3.0 µVrms** per channel | 60s recording, RMS computed per 1s window, mean across windows |
| Noise floor (saline, 0.9% NaCl) | **≤ 5.0 µVrms** per channel | Same method; higher threshold accounts for electrode-saline interface |
| Channel-to-channel isolation | **≥ −40 dB** (baseline, no coupling) | Cross-correlation matrix from 30s baseline epoch |
| DC offset drift | **< 50 µV/min** per channel | Linear regression on 1s-windowed mean over 10-minute baseline |

### 3.3 How Drop Rate Is Computed

```
drop_rate = (frames_expected - frames_received) / frames_expected

where:
  frames_expected = last_frame_id - first_frame_id + 1
  frames_received = count of frames with valid CRC
```

This is implemented in `capture.py::validate_frame_sequence()` and
reported in `CaptureStats.drop_rate`.

**Frame ID gap detection:** Each frame carries a 32-bit monotonic
`frame_id`. A gap of N in frame_id indicates N−1 dropped frames.
The gap is logged with timestamps for debugging.

---

## 4. Repeatability Specification

| Metric | Requirement | Method |
|---|---|---|
| Noise floor CV across sessions | **< 15%** | Same electrode array, same saline, same temperature ±2°C |
| Detection latency ICC | **> 0.7** | Intraclass correlation across replication trials (Session 4 vs 1–3) |
| Trial-order invariance | **Same result distribution** (p > 0.05, KS test) | Compare analysis output for two orderings of same trial set |

### Computational Repeatability

| Aspect | Enforcement |
|---|---|
| Random seeds | All generators and classifiers use explicit `seed` parameter |
| Dataset hashes | SHA-256 of training .npz verified before each analysis run |
| Software versions | `requirements.txt` pinned; Python version recorded in metadata |
| Figure reproduction | `python analysis/eval_report.py --out out/ --seed 42` produces identical output |

---

## 5. Acceptance Test Procedure

Run after every hardware change, cable swap, or firmware update.

### 5.1 Quick Smoke Test (< 2 min)

```bash
# Verify capture pipeline works end-to-end
python hardware/meadaq-64ch/host/capture.py --smoke-test
```

**Pass:** 101 valid frames, 0 CRC failures, 5 detected drops (intentional gap).

### 5.2 Noise Floor Test (5 min)

1. Short all 14 inputs to REF at the connector.
2. Record 60 seconds at 20 kS/s.
3. Run: `python analysis/neural_metrics.py --input recording.npz --check-noise`
4. **Pass:** All 14 channels ≤ 3.0 µVrms.

### 5.3 Sustained Capture Test (10 min)

1. Connect to saline phantom.
2. Record 10 minutes continuously.
3. Run: `python hardware/meadaq-64ch/host/capture.py recording.bin --offline --stats-only`
4. **Pass:** drop_rate < 0.1%, CRC failures = 0, no timestamp violations.

### 5.4 Detection Pipeline Test (5 min)

1. While recording, apply known perturbation at t=30s (e.g., swap saline).
2. Run analysis pipeline.
3. **Pass:** Perturbation detected with latency < 5s.

---

## 6. Failure Modes and Escalation

| Symptom | Likely Cause | Action |
|---|---|---|
| CRC failures > 0 | SPI bus noise, cold solder joint | Inspect solder joints; add decoupling; reduce SPI clock |
| Drop rate > 0.1% | USB buffer overflow, slow host | Check USB connection; close background processes; reduce fs |
| Noise > 5 µVrms | Poor shielding, ground loop, bad electrode | Check Faraday cage; verify GND connections; replace electrode wire |
| No frames received | SPI dead, chip not powered | Check 3.3V rail; verify MISO signal on scope; re-solder U1 |
| Timestamp non-monotonic | FPGA counter bug or USB reordering | Check firmware; verify single-threaded capture; reduce fs |

---

## 7. Version History

| Version | Date | Change |
|---|---|---|
| 1.0 | 2026-03-02 | Initial contract. USB CDC bring-up path, 14ch @ 20kS/s, hard integrity specs. |

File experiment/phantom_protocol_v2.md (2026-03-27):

# Phantom Validation Protocol v2.0

**Project:** BCIInterface — 14-Channel Electrophysiology Platform  
**Date:** 2026-03-02 (supersedes v1.0 2026-03-01)  
**PI:** A. Harshi  
**Status:** LOCKED — aligns with two-stage classifier labels  
**Runtime contract:** `experiment/device_runtime_contract_v1.md`

---

## 1. Scientific Claim (Revised)

> "A low-cost neural acquisition + computational QA stack that detects
> and classifies electrophysiological perturbations and separates
> 'instrument artifacts' from 'suppression-like signatures†', enabling
> scalable screening / validation workflows."

**†Proxy class disclaimer:** "Suppression-like" refers to signal
patterns (amplitude reduction, burst fragmentation, spectral
redistribution) that *resemble* biological suppression but are
produced here under phantom (non-biological) conditions. No
neurons are present. This is a platform validation study, not
a neurotoxicity claim.

---

## 2. Classification Label Alignment

Phantom trials are designed to produce signals that the two-stage
classifier will categorize. Every trial maps to a **training label**.

### 2.1 Artifact Trials (Stage 2 label: "Artifact")

These are instrumentation failure modes the system must classify
correctly as *not* biological.

| Trial type | Phantom method | Classifier label | Generator match |
|---|---|---|---|
| **A1: Impedance drift** | Swap saline concentration (0.9% → 0.3% → 0.1%) | `impedance_drift` | `generate_impedance_drift()` |
| **A2: Broadband noise** | Inject white noise via function generator (10/50/100 mVpp through 1 MΩ) | `broadband_noise` | `generate_broadband_noise()` |
| **A3: Line interference** | Remove Faraday cage lid during recording (60 Hz pickup) | `line_interference` | `generate_line_interference()` |
| **A4: Crosstalk / coupling** | Bridge two electrodes with resistor (1MΩ / 100kΩ / 10kΩ) | `crosstalk_coupling` | `generate_crosstalk()` |

### 2.2 Suppression-Like† Proxy Trials (Stage 2 label: "Suppression-Like†")

These trials produce signal patterns that *look like* biological
suppression but are created by physical manipulation of the phantom.

| Trial type | Phantom method | Signal effect | Classifier label | Generator match |
|---|---|---|---|---|
| **S1: Amplitude suppression proxy** | Increase electrode impedance by partially lifting electrodes from saline (raise 2mm) | Amplitude ↓ without noise ↑ (mimics `spike_suppression`) | `spike_suppression` | `generate_spike_suppression()` |
| **S2: Burst collapse proxy** | Inject pulse train (5 Hz, 1ms pulses) then suddenly stop at t=onset | Loss of periodic structure (mimics `burst_collapse`) | `burst_collapse` | `generate_burst_collapse()` |
| **S3: Spectral shift proxy** | Add low-pass RC filter inline (10 kΩ + 1 nF → fc ≈ 16 kHz, then 10 nF → fc ≈ 1.6 kHz) | High-frequency power ↓, spectral slope change | `spectral_shift` | `generate_spectral_shift()` |
| **S4: Mixed suppression proxy** | Combine S1 + S2: partial electrode lift + stop pulse train | Amplitude ↓ + periodic structure loss + mild spectral change | `mixed_neurotox` | `generate_mixed_neurotox()` |

### 2.3 Baseline Trials

| Trial type | Phantom method | Expected result |
|---|---|---|
| **B: Baseline** | No manipulation; electrodes in 0.9% saline, Faraday cage closed | No detection (Stage 1 silent), FP rate measurement |

### 2.4 Adversarial Trials (Stress Tests)

These intentionally combine artifact + suppression-like signatures to
test classifier robustness under ambiguous conditions.

| Trial type | Phantom method | Expected challenge |
|---|---|---|
| **X1: Drift + coupling** | Swap saline + bridge electrodes simultaneously | Compound artifact; should still classify as artifact |
| **X2: Suppression + 60 Hz** | Partial electrode lift + remove cage lid | Suppression-like signal with artifact overlay; should classify as suppression-like |

---

## 3. Trial Matrix

### 3.1 Session Structure

Each trial follows the standard epoch structure from the runtime contract:

```
|← 30s baseline →|← ~10s transition →|← 30s perturbed →|← 30s recovery →|
     epoch 1              (mark)            epoch 2           epoch 3
```

Total per trial: **100 seconds**. Mark exact onset time to nearest second.

### 3.2 Session Schedule

| Session | Type | Conditions | Levels | Trials/level | Total trials |
|---|---|---|---|---|---|
| 0 | Baseline (B) | 1 | — | 5 | **5** |
| 1 | Artifact A1 (impedance) | 1 | 3 (0.3%, 0.1%, dry) | 3 each | **9** |
| 2 | Artifact A2 (noise) | 1 | 3 (10, 50, 100 mVpp) | 3 each | **9** |
| 3 | Artifact A3 (line) | 1 | 2 (partial open, full open) | 3 each | **6** |
| 4 | Artifact A4 (coupling) | 1 | 3 (1MΩ, 100kΩ, 10kΩ) | 3 each | **9** |
| 5 | Suppression S1 (amplitude) | 1 | 3 (1mm, 2mm, 3mm lift) | 3 each | **9** |
| 6 | Suppression S2 (burst) | 1 | 2 (slow stop, abrupt stop) | 3 each | **6** |
| 7 | Suppression S3 (spectral) | 1 | 2 (1.6kHz, 500Hz cutoff) | 3 each | **6** |
| 8 | Suppression S4 (mixed) | 1 | 2 (mild, severe) | 3 each | **6** |
| 9 | Adversarial X1, X2 | 2 | 1 each | 3 each | **6** |
| 10 | Replication | Best 3 conditions from S1–S4 | 3 | 3 each | **9** |
| | | | | **Total** | **80** |

**Total recording time:** 80 trials × 100s = ~2.2 hours of data.

### 3.3 Randomization

Within each session, randomize trial order using pre-generated seed:

```bash
python experiment/generate_trial_order.py --seed 42 --protocol v2
```

---

## 4. Equipment

| Item | Role | Settings |
|---|---|---|
| Intan RHD2000 USB interface board | SPI host + ADC readout | 20 kS/s, 14 channels |
| AFE Headstage v1 PCB | DUT | 3.3V via Intan board |
| Bench DC power supply | Backup power verify | 3.3V, 50 mA limit |
| Function generator | Perturbation A2, S2 | White noise / pulse train |
| Oscilloscope | Signal verification | ≥ 20 MHz BW |
| Multimeter | Impedance / resistance | Ω mode |
| Resistors (1MΩ, 100kΩ, 10kΩ) | Coupling bridges (A4) | Breadboard-mounted |
| RC filter (10kΩ + 1nF / 10nF) | Spectral shift (S3) | Inline with electrode |
| 3 saline solutions (0.9%, 0.3%, 0.1%) | Impedance levels | Distilled water + NaCl |
| Wire electrode array (14-wire) | Phantom electrodes | 2×7 grid, 3mm spacing |
| Faraday cage (aluminum foil) | Shielding control | Removable lid for A3 |
| Micrometer stage or ruler | Electrode lift (S1) | mm-precision lift |

---

## 5. Recording Procedure (Per Trial)

1. Verify Faraday cage closed (unless A3).
2. Record temperature (±0.5°C).
3. Start Intan recording: 20 kS/s, 14 channels, `.rhd` output.
4. Wait **30 seconds** (baseline epoch).
5. **Apply perturbation** — log exact time in session spreadsheet.
6. Wait **30 seconds** (perturbed epoch).
7. Remove perturbation / restore baseline.
8. Wait **30 seconds** (recovery epoch).
9. Stop recording. Total ~100s.
10. Save: `S{session}_T{trial}_{type}_{level}.rhd`
11. Log trial in `experiment/session_log_v2.csv`.

---

## 6. File Naming Convention

```
data/
  raw/
    S00_T01_baseline_none.rhd
    S01_T01_impedance_0.3pct.rhd
    S01_T02_impedance_0.1pct.rhd
    S02_T01_noise_10mV.rhd
    ...
    S05_T01_suppression_1mm.rhd
    ...
    S09_T01_adversarial_drift_coupling.rhd
    S09_T04_adversarial_suppression_60hz.rhd
    ...
  processed/
    S01_T01_impedance_0.3pct.npz
    ...
```

---

## 7. Analysis Pipeline

### 7.1 Offline Processing

```bash
# Convert all .rhd → .npz
python analysis/rhd_loader.py --input data/raw/ --output data/processed/

# Run session analyzer
python analysis/session_analyzer.py \
    --input data/processed/ \
    --log experiment/session_log_v2.csv \
    --onset 30 \
    --output results/session_results.csv

# Generate competition figures
python analysis/eval_report.py \
    --out out/figures/ \
    --seed 42 \
    --dpi 300
```

### 7.2 Validation Against Phantom Data

For each trial, the analysis pipeline:

1. **Stage 1 (CUSUM):** Detects onset of perturbation.
   - Compare detected onset vs. logged onset → latency.
   - FP rate measured on baseline trials.

2. **Stage 2 (RandomForest):** Classifies detected perturbation.
   - Compare predicted label vs. ground-truth trial type.
   - Binary: artifact vs. suppression-like.
   - Multi-class: specific perturbation type.

3. **Concordance:** Compare classifier output (trained on synthetic data)
   against actual phantom trial labels.
   - This is the key result: *does the model trained on synthetic
     generators actually work on real hardware recordings?*

---

## 8. Primary Endpoints

### 8.1 Detection (Stage 1)

| Metric | Target | Measurement |
|---|---|---|
| True positive rate | ≥ 90% | Across all perturbation trials |
| False positive rate | ≤ 5% | Baseline trials only |
| Detection latency | ≤ 5 seconds (median) | Time from true onset to CUSUM alarm |
| Detection latency IQR | ≤ 3 seconds | Consistency measure |

### 8.2 Classification (Stage 2)

| Metric | Target | Measurement |
|---|---|---|
| Binary accuracy (artifact vs suppression-like) | ≥ 80% | Leave-one-out CV on phantom data |
| Binary AUROC | ≥ 0.85 | — |
| Concordance: synthetic → phantom | ≥ 70% | Train on synthetic, test on phantom |

### 8.3 Adversarial Robustness

| Metric | Target |
|---|---|
| Correct classification on X1 (drift+coupling) | ≥ 2/3 trials classified as "artifact" |
| Correct classification on X2 (suppression+60Hz) | ≥ 2/3 trials classified as "suppression-like" |

---

## 9. Statistical Analysis Plan

### 9.1 Per-Trial

- `rms_baseline`: mean RMS over baseline epoch (14 channels → scalar)
- `rms_perturbed`: mean RMS over perturbed epoch
- `rms_ratio`: perturbed / baseline
- `detection_latency_s`: onset to CUSUM alarm (NaN if missed)
- `detected`: boolean
- `binary_prediction`: "artifact" or "suppression-like"
- `multi_prediction`: specific perturbation type

### 9.2 Group-Level

1. **Detection rate:** proportion ± 95% Wilson CI per perturbation type.
2. **Latency:** median ± IQR per type.
3. **Effect size:** Wilcoxon signed-rank (baseline vs perturbed RMS).
4. **Concordance:** confusion matrix (phantom label vs classifier prediction).
5. **Adversarial:** proportion correctly classified ± exact binomial CI.

### 9.3 Multiple Comparisons

- 8 perturbation types + 2 adversarial = 10 comparisons.
- Bonferroni-corrected α = 0.05 / 10 = 0.005.

---

## 10. Footnote Policy

All user-facing outputs (figures, tables, text) must include:

> **†** Proxy label. "Suppression-like" describes signal patterns
> (amplitude reduction, burst fragmentation, spectral redistribution)
> produced under phantom conditions. No neurons are present. This
> is a platform validation study.

This footnote appears on:
- All evaluation figures (watermark: "SIMULATION STUDY")
- Confusion matrix axis labels
- Results tables
- Abstract / poster text

---

## 11. Success Criteria Summary

| Gate | Criterion | Verdict |
|---|---|---|
| **GO** | TP ≥ 90%, FP ≤ 5%, latency ≤ 5s, binary accuracy ≥ 80% | Proceed to write-up |
| **PARTIAL** | TP ≥ 70% OR binary accuracy ≥ 70% | Report with limitations |
| **NO-GO** | TP < 70% AND accuracy < 70% | Debug hardware, retake data |

---

## 12. Risk Mitigation

| Risk | Probability | Impact | Mitigation |
|---|---|---|---|
| PCB arrives late | Medium | Delays all data | Ordered JLCPCB rush; backup plan: computational-only submission |
| QFN solder bridge | Medium | Board dead | Order 5 boards; inspect under microscope before power-on |
| Noise floor > 5 µVrms | Low | Weak detection | Improve Faraday cage; shorter cables; add ferrite |
| Synthetic ≠ phantom signatures | Medium | Low concordance | Feature importance analysis; retrain on phantom data if needed |
| Saline evaporation | Low | Impedance drift | Cover container; short sessions; monitor level |
| Adversarial trials ambiguous | Medium | Low adversarial accuracy | Accept and report honestly; ambiguity IS the interesting result |

---

## 13. Version History

| Version | Date | Change |
|---|---|---|
| 1.0 | 2026-03-01 | Initial protocol (3 perturbation types, 77 trials) |
| 2.0 | 2026-03-02 | Align with two-stage classifier labels. Add suppression-like proxy trials (S1–S4), adversarial trials (X1–X2), replication session. 80 trials. Proxy label policy enforced. |

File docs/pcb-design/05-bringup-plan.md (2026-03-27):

# 05 - Bring-Up Plan

## Philosophy

**Do not go straight to 128 channels.** If you do, you will have no idea what broke.

Bring-up is systematic. Each phase has a clear pass/fail criterion before proceeding.

---

## Timeline Overview

| Phase | Duration | Description |
|---|---|---|
| 0 | Day 0 | Visual inspection |
| 1 | Day 1-2 | Power verification |
| 2 | Day 2-3 | Clock verification |
| 3 | Day 3-4 | Digital link verification |
| 4 | Day 4-5 | Analog noise floor (inputs shorted) |
| 5 | Day 5-7 | Calibration injection and channel mapping |
| 6 | Day 7-10 | Scale-up (8→32→64→128) |
| 7 | Day 10+ | Full system validation |

---

## Phase 0: Visual Inspection (Before Power)

### Checklist

- [ ] No obvious solder bridges
- [ ] All components placed and oriented correctly
- [ ] No missing components
- [ ] Connector pins not bent
- [ ] No PCB damage (scratches to traces)

### Tools
- Magnifying glass or microscope
- Good lighting

### Pass Criteria
- No visible defects
- All critical components present

---

## Phase 1: Power Verification

### Equipment
- Bench power supply with current limiting
- Multimeter
- Oscilloscope (for noise measurement)

### Procedure

#### Step 1.1: Initial Power-Up (Current Limited)
```
1. Set bench supply to expected input voltage (e.g., 5V)
2. Set current limit to 50 mA (well below expected draw)
3. Connect to board (with load switches OFF if present)
4. Monitor current draw
```

**Expected:** <10 mA quiescent (regulators only, no load)
**Red flag:** Current limit hit immediately → short circuit

#### Step 1.2: Rail Verification
```
Measure each rail at test point:
- VIN: ______V (expected: 5.0V)
- AVDD: ______V (expected: 3.3V)
- DVDD: ______V (expected: 3.3V)
- VREF: ______V (expected: per design)
- VCORE: ______V (expected: 1.2V, if present)
```

**Pass criteria:** All rails within ±5% of nominal

#### Step 1.3: Rail Noise Measurement
```
Using oscilloscope (AC coupled, 20 MHz BW limit):
Measure ripple/noise at each rail test point.

- AVDD ripple: ______mVpp (target: <10 mVpp)
- DVDD ripple: ______mVpp (target: <50 mVpp)
- VREF noise: ______µVrms (target: <100 µVrms)
```

#### Step 1.4: Thermal Check
```
After 5 minutes at full power:
- Touch-test all regulators (should be warm, not hot)
- Thermal camera if available
- Any component >60°C is a concern
```

### Phase 1 Sign-Off

| Item | Pass | Fail | Notes |
|---|---|---|---|
| No short circuits | ☐ | ☐ | |
| All rails correct voltage | ☐ | ☐ | |
| AVDD noise acceptable | ☐ | ☐ | |
| No thermal issues | ☐ | ☐ | |

**Proceed to Phase 2 only if all pass.**

---

## Phase 2: Clock Verification

### Equipment
- Oscilloscope (≥100 MHz BW)
- Frequency counter (optional)

### Procedure

#### Step 2.1: Clock Presence
```
Probe MCLK test point:
- Frequency: ______MHz (expected: per design)
- Amplitude: ______Vpp (expected: rail-to-rail or per spec)
- Waveform: Clean square/sine (no ringing, no missing cycles)
```

#### Step 2.2: Clock Quality
```
Using oscilloscope:
- Check for overshoot/undershoot: <10% of amplitude
- Check for ringing: settled within one cycle
- Verify no missing clock edges (run for 1 minute)
```

#### Step 2.3: Clock at AFE Input
```
If accessible, probe clock at AFE MCLK pin:
- Confirm same frequency
- Amplitude appropriate for IC input
- No excessive reflections
```

### Phase 2 Sign-Off

| Item | Pass | Fail | Notes |
|---|---|---|---|
| Clock present | ☐ | ☐ | |
| Correct frequency | ☐ | ☐ | |
| Clean waveform | ☐ | ☐ | |
| Stable (1 min) | ☐ | ☐ | |

---

## Phase 3: Digital Link Verification

### Equipment
- Host computer with software
- Logic analyzer (optional)
- Oscilloscope

### Procedure

#### Step 3.1: Basic Communication
```
1. Connect board to host
2. Enumerate device (USB) or establish connection (Ethernet)
3. Send basic command (e.g., read chip ID)
```

**Expected:** AFE chip ID matches datasheet value

#### Step 3.2: Register Access
```
1. Write known pattern to writable register
2. Read back
3. Verify match
```

**Example:**
```
Write: 0xABCD to test register
Read: _______ (expected: 0xABCD)
```

#### Step 3.3: Continuous Data Transfer
```
1. Configure AFE for minimal data (e.g., 1 channel, low rate)
2. Start acquisition
3. Verify packets received
4. Check sequence numbers are sequential
5. Run for 1 minute
```

**Pass criteria:**
- Packets received continuously
- No sequence number gaps
- No CRC errors

#### Step 3.4: Throughput Test
```
1. Configure for full bandwidth (128 ch, target sample rate)
2. Run for 1 minute
3. Count dropped packets
```

**Pass criteria:** 0 dropped packets in 1 minute

### Phase 3 Sign-Off

| Item | Pass | Fail | Notes |
|---|---|---|---|
| Device enumerates/connects | ☐ | ☐ | |
| Chip ID correct | ☐ | ☐ | |
| Register R/W works | ☐ | ☐ | |
| Continuous data OK | ☐ | ☐ | |
| Full throughput achieved | ☐ | ☐ | |

---

## Phase 4: Analog Noise Floor

### Equipment
- Acquisition software with noise analysis
- Oscilloscope (for debugging)

### Setup
```
1. Enable input shorting (all inputs to reference)
2. Disable calibration injection
3. Configure AFE for target bandwidth and sample rate
4. Acquire data for all channels
```

### Procedure

#### Step 4.1: Measure Input-Referred Noise
```
1. Acquire 10 seconds of data (inputs shorted)
2. Compute RMS noise per channel
3. Compare to specification
```

**Calculation:**
```
For each channel:
  noise_rms = std(samples) × (Vref / 2^bits) × 1e6  [in µVrms]
```

**Expected:** < target noise floor (e.g., <5 µVrms)

#### Step 4.2: Noise Spectrum Analysis
```
1. Compute FFT of shorted-input data
2. Look for:
   - 50/60 Hz line noise (and harmonics)
   - Clock frequency spurs
   - Broadband elevation
```

**Pass criteria:**
- No narrowband spurs >3 dB above noise floor
- 50/60 Hz < specification
- Spectrum shape matches expected (1/f + white)

#### Step 4.3: Channel-to-Channel Consistency
```
1. Compare noise across all channels
2. Flag any channel >2× median noise
```

**Pass criteria:** All channels within 2× of each other

### Noise Troubleshooting Guide

| Symptom | Likely Cause | Action |
|---|---|---|
| All channels high noise | Power supply issue | Check AVDD noise |
| 50/60 Hz spike | Ground loop | Check ground connections |
| Clock frequency spike | Digital coupling | Review layout, shielding |
| One channel bad | Solder issue or ESD damage | Inspect, reflow |
| Noise increases over time | Thermal issue | Check regulator temp |

### Phase 4 Sign-Off

| Item | Pass | Fail | Notes |
|---|---|---|---|
| Average noise < spec | ☐ | ☐ | Value: ___µVrms |
| No line frequency spurs | ☐ | ☐ | |
| No clock spurs | ☐ | ☐ | |
| All channels consistent | ☐ | ☐ | |

---

## Phase 5: Calibration Injection

### Equipment
- Signal generator or DAC output
- Acquisition software

### Setup
```
1. Disable input shorting
2. Enable calibration injection
3. Configure injection signal (e.g., 1 kHz sine, 100 µVpp)
```

### Procedure

#### Step 5.1: Injection Signal Verification
```
1. Probe CAL_INJECT test point with oscilloscope
2. Verify amplitude and frequency
```

**Expected:** 
- Frequency: ______ Hz (as configured)
- Amplitude: ______ µVpp (per attenuation calculation)

#### Step 5.2: Single Channel Capture
```
1. Route injection to one channel
2. Acquire data
3. Verify signal appears in correct channel
4. Verify amplitude matches expectation
```

**Pass criteria:**
- Signal in correct channel
- Amplitude within ±10% of expected
- SNR > 20 dB

#### Step 5.3: Channel Mapping
```
1. Inject to each channel sequentially (or all simultaneously)
2. Verify each input maps to expected data channel
3. Create mapping table:
```

| Connector Pin | AFE Input | Data Channel | Status |
|---|---|---|---|
| 1 | IN0 | CH0 | ☐ OK |
| 2 | IN1 | CH1 | ☐ OK |
| ... | ... | ... | ... |
| 128 | IN127 | CH127 | ☐ OK |

#### Step 5.4: Frequency Response (Optional)
```
1. Sweep injection frequency (10 Hz to 10 kHz)
2. Measure amplitude at each frequency
3. Verify bandwidth matches specification
```

**Expected:** -3 dB points at specified HPF and LPF frequencies

### Phase 5 Sign-Off

| Item | Pass | Fail | Notes |
|---|---|---|---|
| Injection signal correct | ☐ | ☐ | |
| Channel mapping verified | ☐ | ☐ | |
| Gain within spec | ☐ | ☐ | |
| Bandwidth within spec | ☐ | ☐ | |

---

## Phase 6: Scale-Up Testing

### Rationale

Do not jump straight to 128 channels. Verify in stages to isolate issues.

### Procedure

#### Step 6.1: 8-Channel Test
```
1. Connect 8 electrodes (or simulate with resistors)
2. Acquire data
3. Verify noise, crosstalk, signal integrity
```

**Crosstalk test:**
- Inject signal on channel 1
- Measure amplitude on channels 2-8
- Crosstalk should be < -40 dB

#### Step 6.2: 32-Channel Test
```
1. Connect 32 electrodes
2. Repeat noise and crosstalk tests
3. Verify digital throughput stable
```

#### Step 6.3: 64-Channel Test
```
1. Connect 64 electrodes
2. Repeat all tests
3. Monitor thermal behavior
```

#### Step 6.4: 128-Channel Test
```
1. Connect all 128 electrodes
2. Final verification of all parameters
```

### Scale-Up Checklist

| Channels | Noise OK | Crosstalk OK | Throughput OK | Thermal OK |
|---|---|---|---|---|
| 8 | ☐ | ☐ | ☐ | ☐ |
| 32 | ☐ | ☐ | ☐ | ☐ |
| 64 | ☐ | ☐ | ☐ | ☐ |
| 128 | ☐ | ☐ | ☐ | ☐ |

---

## Phase 7: Full System Validation

### Tests

#### 7.1: Long-Term Stability
```
1. Run acquisition for 24 hours
2. Monitor for:
   - Dropped packets
   - Noise drift
   - Thermal stability
```

#### 7.2: Environmental
```
If relevant:
- Temperature cycling (bench ambient variation)
- Vibration (tap test)
- EMI susceptibility (bring phone near, etc.)
```

#### 7.3: In-Vitro Test (With Real Electrodes)
```
1. Connect to actual MEA/electrode array
2. Place in saline bath
3. Verify noise floor with real electrode impedances
4. Verify ability to see simulated signals
```

### Final Sign-Off

| Item | Pass | Fail | Notes |
|---|---|---|---|
| 24-hour stability | ☐ | ☐ | |
| Environmental OK | ☐ | ☐ | |
| In-vitro test passed | ☐ | ☐ | |

---

## Debug Appendix

### Common Problems and Solutions

| Problem | Possible Causes | Debug Steps |
|---|---|---|
| No power | Open circuit, blown fuse | Check continuity, inspect solder |
| High noise all channels | Power supply noise, grounding | Scope power rails, check grounds |
| One channel noisy | Solder defect, ESD damage | Visual inspect, reflow |
| Digital link fails | Termination, clock | Check eye diagram, clock quality |
| Crosstalk | Layout, common impedance | Review routing, add shielding |
| Intermittent | Mechanical, thermal | Flex test, thermal cycle |

### Isolation Techniques

1. **Analog-Digital Isolation:**
   Remove isolation resistor between analog and digital power
   → Power analog only → measure noise
   → If noise is low, problem is digital coupling

2. **Per-Channel Isolation:**
   Disconnect suspect channel from AFE input
   → If noise drops, problem is input network
   → If noise stays, problem is AFE or downstream

3. **Clock Isolation:**
   Temporarily stop clock (put AFE in standby)
   → If noise drops dramatically, clock coupling is the issue

---

## Documentation Template

### Bring-Up Report

```
Board ID: _______________
Date: _______________
Engineer: _______________

Phase 1 - Power:
  VIN: _____V  AVDD: _____V  DVDD: _____V  VREF: _____V
  AVDD noise: _____mVpp
  Current draw: _____mA
  Status: PASS / FAIL

Phase 2 - Clock:
  Frequency: _____MHz
  Status: PASS / FAIL

Phase 3 - Digital:
  Chip ID: _____
  Throughput: _____MB/s
  Dropped packets (1 min): _____
  Status: PASS / FAIL

Phase 4 - Noise:
  Average noise (shorted): _____µVrms
  Worst channel: _____µVrms
  Line noise: _____dB
  Status: PASS / FAIL

Phase 5 - Calibration:
  Channel mapping verified: YES / NO
  Gain error: _____%
  Status: PASS / FAIL

Phase 6 - Scale-Up:
  128-channel status: PASS / FAIL

Phase 7 - Validation:
  24-hour test: PASS / FAIL

OVERALL STATUS: _______________

Notes:
_________________________________
_________________________________
_________________________________
```

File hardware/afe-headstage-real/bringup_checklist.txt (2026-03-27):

================================================================================
 FIRST-ARTICLE INSPECTION & BRING-UP CHECKLIST
 Board:    AFE Headstage v1 (afe-headstage-v1)
 Revision: 1.0
 Date:     2026-03-01
 Contact:  [engineer email]
================================================================================

PURPOSE
-------
  This checklist shall be executed on the FIRST board of every fabrication
  lot before committing the lot to assembly.  Record results in writing.
  Any FAIL halts the lot.

================================================================================
 PHASE 1 — BARE BOARD VISUAL INSPECTION (before assembly)
================================================================================

Equipment: stereo microscope (≥ 20×), backlight, calipers

  [ ] 1.1  Board dimensions: 30.0 × 24.0 mm ±0.1 mm
  [ ] 1.2  4-layer stackup confirmed (view board edge cross-section or
           vendor layer count report)
  [ ] 1.3  ENIG finish: uniform gold color, no discoloration, no nickel
           bleed-through on pads
  [ ] 1.4  Soldermask: green both sides, no pinholes over copper,
           no mask on exposed pads
  [ ] 1.5  Silkscreen: legible on front, component references readable
  [ ] 1.6  Edge cuts: clean routing, no burrs, no delamination
  [ ] 1.7  Fiducials (if present): centered, clean aperture

--------------------------------------------------------------------------------
 PHASE 2 — VIP INSPECTION AT J5 (CRITICAL)
--------------------------------------------------------------------------------

Equipment: stereo microscope (≥ 40×), coplanarity gauge or profilometer

  [ ] 2.1  All 14 VIP pads at J5 are FLAT — no visible via holes on
           component side
  [ ] 2.2  No dimples > 25 µm measured by profilometer or coplanarity gauge
  [ ] 2.3  No epoxy bleed beyond pad boundary
  [ ] 2.4  No copper cap lifting, delamination, or discoloration
  [ ] 2.5  Pad surfaces are solderable (no oxidation, no residue)
  [ ] 2.6  Compare VIP pad locations against vip_vias.csv coordinates —
           all 14 accounted for

  If ANY of 2.1–2.6 FAIL → reject lot, contact fabricator, request
  cross-section (see Phase 3).

--------------------------------------------------------------------------------
 PHASE 3 — DESTRUCTIVE CROSS-SECTION (MANDATORY for first lot)
--------------------------------------------------------------------------------

Equipment: vendor cross-section service or in-house metallographic prep

  REQUIREMENT: One sample board from first lot SHALL be cross-sectioned
  through J5 VIP region (at least 3 of 14 VIP vias in the cut plane).
  This is destructive and mandatory. Do not skip. Do not defer.
  Assembly of remaining boards shall not proceed until cross-section
  results are reviewed and accepted.

  [ ] 3.1  Via barrel fully filled with epoxy (no voids > 25 µm)
  [ ] 3.2  Copper cap continuous and bonded to epoxy surface
  [ ] 3.3  Cap thickness ≥ 15 µm
  [ ] 3.4  No barrel cracking or delamination
  [ ] 3.5  Plating uniform on barrel walls

  Record: attach micrograph images to lot traveler.

================================================================================
 PHASE 4 — BARE BOARD ELECTRICAL TEST
================================================================================

Equipment: multimeter (DMM), or continuity tester

  [ ] 4.1  GND continuity: probe any two GND vias on opposite sides of
           board — shall read < 1 Ω
  [ ] 4.2  Power rails: probe VDD33 net at U1 pad vs nearest decoupling
           cap pad — shall read < 1 Ω
  [ ] 4.3  No shorts between adjacent electrode nets:
           For each pair (CHn, CHn+1) where n = 9..21:
             probe J5 pin for CHn and J5 pin for CHn+1
             shall read OPEN (> 10 MΩ)
  [ ] 4.4  No short between any electrode net and GND:
           For each CH9..CH22:
             probe J5 pad for CHn and any GND pad
             shall read OPEN (> 10 MΩ)
  [ ] 4.5  U1 thermal pad to GND: < 1 Ω (through thermal vias)

================================================================================
 PHASE 5 — POST-ASSEMBLY CHANNEL CONTINUITY
================================================================================

Equipment: DMM, pogo-pin test jig (recommended), or fine-pitch probes

  Precondition: U1 (RHD2132) and J5 (Omnetics A79024) are soldered.

  For each channel CH9 through CH22:

  [ ] 5.1  Continuity: J5 pin → U1 input pin
           Expected: < 5 Ω (trace + via + pad resistance)
           Record measured value per channel.

  [ ] 5.2  Isolation: each channel to GND
           Expected: > 10 MΩ
           Record measured value per channel.

  Channel Map (J5 pin → net → U1 pin):

    J5 Pin | Net  | U1 Pin | Continuity (Ω) | Isolation (MΩ)
    -------+------+--------+-----------------+---------------
    10     | CH9  | [TBD]  |                 |
    11     | CH10 | [TBD]  |                 |
    12     | CH11 | [TBD]  |                 |
    13     | CH12 | [TBD]  |                 |
    14     | CH13 | [TBD]  |                 |
    15     | CH14 | [TBD]  |                 |
    16     | CH15 | [TBD]  |                 |
    17     | CH16 | [TBD]  |                 |
    18     | CH17 | [TBD]  |                 |
    19     | CH18 | [TBD]  |                 |
    20     | CH19 | [TBD]  |                 |
    21     | CH20 | [TBD]  |                 |
    22     | CH21 | [TBD]  |                 |
    23     | CH22 | [TBD]  |                 |

  PASS criteria: all channels < 5 Ω continuity, all channels > 10 MΩ isolation.
  Any FAIL: inspect solder joints under microscope, rework or reject.

================================================================================
 PHASE 6 — CONNECTOR MECHANICAL INTEGRITY
================================================================================

Equipment: stereo microscope, tweezers

  [ ] 6.1  J5 body seated flat against board (no tilt, no lifted pads)
  [ ] 6.2  All J5 solder fillets visible under microscope (no bridging,
           no cold joints, no insufficient solder)
  [ ] 6.3  Wiggle test: apply gentle lateral force to J5 body with tweezers.
           No pad lifting. No audible cracking. No resistance change
           on channels during wiggle (monitor with DMM).
  [ ] 6.4  Mating test: insert and remove Omnetics mating connector 3×.
           Verify continuity on all 14 channels after each cycle.
  [ ] 6.5  U1 QFN inspection: no solder bridges on exposed QFN leads.
           Thermal pad: solder wetting visible at edges (X-ray if available).

================================================================================
 PHASE 7 — FUNCTIONAL SMOKE TEST
================================================================================

Equipment: bench supply (3.3V, current-limited to 100 mA), scope/logic analyzer

  [ ] 7.1  Apply 3.3 V to VDD33 rail. Current draw shall be < 20 mA
           (RHD2132 typical idle: ~8 mA). If > 50 mA → power off immediately.
  [ ] 7.2  SPI communication: send READ register command to U1.
           Verify correct device ID response.
  [ ] 7.3  Channel noise floor: configure U1 for DC-coupled input,
           read back 1000 samples per channel.
           RMS noise shall be < 5 µVrms (typical for RHD2132).
  [ ] 7.4  No latch-up: power cycle 5× with 1s on / 1s off.
           Current shall return to baseline each time.

================================================================================
 SIGN-OFF
================================================================================

  Inspector:       ________________________  Date: ____________

  All phases PASS:  [ ] YES   [ ] NO — see attached deviation report

  Lot disposition:  [ ] ACCEPT   [ ] REJECT   [ ] ACCEPT WITH DEVIATION

  Notes:
  _____________________________________________________________________
  _____________________________________________________________________
  _____________________________________________________________________

================================================================================
 END OF CHECKLIST
================================================================================

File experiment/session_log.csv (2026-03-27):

session | trial | perturbation_type | perturbation_level | onset_time_s | temperature_C | filename | notes
0 | 1 | baseline | none | 30.0 |  | S0_T01_baseline_none.rhd | baseline characterization
0 | 2 | baseline | none | 30.0 |  | S0_T02_baseline_none.rhd | baseline characterization
0 | 3 | baseline | none | 30.0 |  | S0_T03_baseline_none.rhd | baseline characterization
0 | 4 | baseline | none | 30.0 |  | S0_T04_baseline_none.rhd | baseline characterization
0 | 5 | baseline | none | 30.0 |  | S0_T05_baseline_none.rhd | baseline characterization
1 | 1 | impedance | 0.3pct | 30.0 |  | S1_T01_impedance_0.3pct.rhd
1 | 2 | impedance | 0.1pct | 30.0 |  | S1_T02_impedance_0.1pct.rhd
1 | 3 | impedance | 0.3pct | 30.0 |  | S1_T03_impedance_0.3pct.rhd
1 | 4 | impedance | 0.3pct | 30.0 |  | S1_T04_impedance_0.3pct.rhd
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

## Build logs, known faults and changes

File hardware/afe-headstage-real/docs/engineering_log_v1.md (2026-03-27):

# v1 RHD2132 Headstage — Engineering Log

**Rev:** 1.1 · **Date:** 2026-02-27 · **Status:** Pre-routing, all gates green

This log documents bugs found, root causes, fixes applied, and verification
gates established during script-generated schematic + PCB development.
It is the "what went wrong and how we proved it's right" companion to
`design_notes_v1.md`.

---

## 0. Reproducibility

### 0.1 Environment

| Tool | Version | Notes |
|---|---|---|
| KiCad CLI | 9.0.7 | `/opt/homebrew/bin/kicad-cli` |
| Python | 3.14.3 | System python3 via Homebrew |
| pytest | 9.0.2 | |
| Ruff | 0.15.2 (9d18ee911 2026-02-19) | |
| OS | macOS 15.5 (Darwin 24.5.0 arm64) | Apple Silicon |

### 0.2 Reproduce clean state from scratch

All commands run from `hardware/afe-headstage-real/`:

```bash
# 1. Generate schematic
python3 gen_schematic_v1_rhd2132.py

# 2. Run ERC (must be 0 errors, 0 warnings)
kicad-cli sch erc --format json --severity-all \
    -o erc_report.json afe-headstage-v1.kicad_sch

# 3. Export netlist (for net membership verification)
kicad-cli sch export netlist \
    -o afe-headstage-v1.xml afe-headstage-v1.kicad_sch

# 4. Generate PCB
python3 gen_pcb_v1.py

# 5. Run DRC with schematic parity (must be 0 parity, 0 electrical)
kicad-cli pcb drc --schematic-parity --format json \
    -o drc_report.json afe-headstage-v1.kicad_pcb

# 6. Run full test suite (must be 97/97)
python3 -m pytest test_parse_drc.py test_schematic_invariants.py -v
```

### 0.3 Event timeline

| Date | Commit | Event |
|---|---|---|
| 2026-02-26 | — | Initial schematic + PCB generators, CI guardrails (27 tests) |
| 2026-02-26 | — | pin_abs() rot=90/270 swap fix, removed PCB net swap hacks |
| 2026-02-26 | — | REF_ELEC connectivity bug found — colinear overlap root cause |
| 2026-02-26 | — | 5 colinear overlaps fixed, ERC 0/0 achieved |
| 2026-02-27 | — | Net membership tests (12 nets), colinear lint on .kicad_sch output |
| 2026-02-27 | — | Parity + electrical DRC gates, closed-world DRC type enforcement |
| 2026-02-27 | — | Net class enforcement (Gate A), EP invariants (Gate B) |
| 2026-02-27 | — | ELEC_TEST → ELECTRODE, ADC_ref → POWER net class fixes |
| 2026-02-27 | 1f64324 | Pre-routing freeze: 97/97 tests green |

---

## 1. Schematic / PCB Correctness Fixes

### 1.1 Net naming mismatches

**Symptom:** Schematic↔PCB parity DRC produced spurious violations.
**Root cause:** AVDD label vs global label inconsistency; `ADC_ref` global
label missing from schematic.
**Fix:** Unified all net names between schematic generator and PCB generator.

### 1.2 `pin_abs()` rotation formula was wrong

**Symptom:** PCB pad-to-net assignments required ad-hoc pin/net swaps to
produce correct connectivity.
**Root cause:** The rot=90 and rot=270 formulas in `pin_abs()` were swapped.
The function computes KiCad schematic coordinates from symbol-local pin
coordinates; getting 90/270 confused silently produces wrong wire endpoints.
**Fix:** Corrected formulas, removed all swap hacks. Verified against KiCad
wire endpoint positions for Device:R, FerriteBead, and RHD2132 REF pin.
**Gate:** `TestPinAbsAnchoredToKicad` — 4 tests parse the generated
`.kicad_sch` and verify wire endpoints land on computed pin positions.

### 1.3 Test point numbering drift

**Symptom:** TP4–TP10 in the schematic didn't match PCB expectations.
**Root cause:** Schematic generator placement order diverged from PCB
generator's assumed TP numbering.
**Fix:** Aligned both generators to a single numbering convention.

### 1.4 NC pad net conflicts

**Symptom:** J1 pad 11 (MISO2) and U1 pad 27 (AUXOUT) caused parity
violations as "extra net" / "missing net."
**Root cause:** KiCad expects unconnected pads to have explicit
`unconnected-(Ref-Name-PadN)` net names for clean parity.
**Fix:** Assigned explicit unconnected net names in both generators.

### 1.5 Missing Footprint properties in schematic symbol instances

**Symptom:** Mass `footprint_symbol_mismatch` DRC violations.
**Root cause:** Schematic symbol instances lacked Footprint property fields.
**Fix:** Added Footprint properties to all symbol instances in the schematic
generator.

---

## 2. REF_ELEC Connectivity Bug

This was the most consequential bug found during development.

### 2.1 Symptom

- ERC reported `global_label_dangling` on `REF_ELEC`.
- U1 pin 10 (REF) was not reliably connected to the REF_ELEC net.
- Netlist export showed U1.10 missing from REF_ELEC members.

### 2.2 Wrong hypothesis (rejected)

> "KiCad has a single-sheet quirk where it sometimes misreports global
> label connectivity. The wiring is fine; the warning is cosmetic."

This was wrong. The warning indicated a **real connectivity defect**.
Dismissing tool warnings as "KiCad quirks" without proof is how you
ship open nets.

### 2.3 Actual root cause

The schematic generator produced **overlapping colinear wire segments**.
Two failure modes:

1. **Colinear overlap:** Two wire segments at the same Y-coordinate with
   overlapping X-ranges (beyond a shared endpoint). KiCad's connectivity
   engine splits the overlap region and may assign fragments to different
   nets. This is not a KiCad bug — it's the generator producing
   ambiguous topology that KiCad resolves unpredictably.

2. **Pass-through wire:** A single wire from point A through pin B to
   point C gets split at pin B. The far segment (B→C) may not bind to
   the intended net.

### 2.4 Fix pattern

**Rule: every wire segment connects exactly two electrical vertices.
No pass-through. No overlapping segments.**

Applied to five sites:

| Location | Old topology | New topology |
|---|---|---|
| REF_ELEC | Single wire glabel→U1.REF passing through R1.pin2 | Two segments: glabel→R1.pin2, R1.pin2→U1.REF |
| +3V3 bus (y=25.4) | PWR_FLAG/C2/TP_VDD all extending to fb_in (3 overlaps) | Chain: PWR_FLAG→C2→TP_VDD→fb_in |
| AVDD bus (y=25.4) | C4/TP_AVDD overlapping | Chain: C4→TP_AVDD→AVDD label |
| SPI TPs (x=185.42) | TP_SCLK/TP_MISO at same X (vertical overlap) | TP_MISO offset to different X-column |

### 2.5 Enforcement

| Gate | Method | Assertion |
|---|---|---|
| ERC | `kicad-cli sch erc` JSON | 0 errors, 0 warnings (no allowlisting) |
| Net membership | `kicad-cli sch export netlist` | REF_ELEC = {U1.10, J5.33, TP6.1, R1.2} |
| Colinear overlap | Parse `.kicad_sch` wire segments, O(n²) scan | 0 overlaps |
| Pin not orphaned | Netlist membership | U1.10 not in any `unconnected-*` net |
| R1 grounded | Netlist membership | R1.1 on GND |

---

## 3. Exposed Pad (EP) Reliability

### 3.1 Problem

The original EP implementation had F.Paste on the full 4.8×4.8mm pad.
During reflow, this causes:
- Solder voiding (trapped flux gas)
- Die float / tombstoning on adjacent pads
- Poor thermal coupling

### 3.2 Fix

- **Removed F.Paste** from EP main pad
- Added **16 paste aperture windows** (4×4 grid, 0.9×0.9mm, ~56% coverage)
- Added **9 thermal vias** (3×3 grid, 0.3mm drill, 0.6mm pad)
- All vias **tented front and back** (prevents solder wicking)
- All vias on **GND net**

### 3.3 Gate

`TestEPFootprintInvariants` — 8 tests parse the generated `.kicad_pcb`:

| Test | Locked value |
|---|---|
| EP main pad has no F.Paste | ✓ |
| Paste aperture count | 16 |
| Paste aperture size | 0.9×0.9mm |
| Thermal via count | 9 |
| Thermal via drill | 0.3mm |
| Thermal via pad size | 0.6mm |
| Thermal vias tented | front + back, all 9 |
| Thermal vias on GND | all 9 |

---

## 4. Verification Gate Inventory

### 4.1 Hard gates (must pass before routing)

| Gate | Source | Assertion |
|---|---|---|
| ERC errors | `kicad-cli sch erc` | 0 |
| ERC warnings | `kicad-cli sch erc --severity-all` | 0 |
| Schematic parity | `kicad-cli pcb drc --schematic-parity` | 0 issues |
| Electrical DRC | `kicad-cli pcb drc` JSON classification | All 8 electrical categories = 0 |
| Unknown DRC types | Closed-world check | Every violation type in ELECTRICAL ∪ COSMETIC |
| Net membership | `kicad-cli sch export netlist` | 12 critical nets verified |
| Colinear overlap | Parse `.kicad_sch` wire segments | 0 overlaps |
| Net class: electrode | Parse `.kicad_pro` | CH0–CH31 + REF_ELEC + ELEC_TEST in ELECTRODE |
| Net class: SPI | Parse `.kicad_pro` | 7 SPI nets in DIGITAL_SPI |
| Net class: power | Parse `.kicad_pro` | +3V3, AVDD, ADC_ref in POWER |
| Track width: electrode | Parse `.kicad_pro` | ≤0.15mm |
| Track width: power | Parse `.kicad_pro` | ≥0.3mm |
| EP invariants | Parse `.kicad_pcb` | 8 sub-checks (see §3.3) |

### 4.2 Electrical DRC taxonomy (closed-world)

**Must be zero:**
`shorting_items`, `clearance`, `net_conflict`, `copper_edge_clearance`,
`edge_clearance`, `tracks_crossing`, `via_dangling`, `zone_priority`

**Allowed to float (cosmetic):**
`lib_footprint_mismatch`, `silk_over_copper`, `silk_overlap`,
`silk_edge_clearance`, `courtyards_overlap`

**Any type not in either set → test fails immediately.** This prevents
silent rot when KiCad adds new violation types.

### 4.3 Net class data fixed during development

Two nets were found in Default that should not have been:

| Net | Was | Now | Why |
|-----|-----|----|-----|
| ELEC_TEST | Default | ELECTRODE | Routes to U1 elec_test pin alongside electrode inputs |
| ADC_ref | Default | POWER | Analog reference voltage, needs POWER clearance/width |

### 4.4 Test count

| File | Tests | Category |
|---|---|---|
| `test_parse_drc.py` | 27 | DRC report parsing + CI governance |
| `test_schematic_invariants.py` | 70 | Schematic/PCB structural invariants |
| **Total** | **97** | All passing |

---

## 5. Pre-Routing Freeze Criteria

Routing is not permitted until **all** of the following are true.
This is not a guideline — it is enforced by `test_schematic_invariants.py`.

| # | Criterion | Test | Status |
|---|---|---|---|
| 1 | ERC errors = 0 | `TestErcSeverityGate::test_zero_erc_errors` | ✅ |
| 2 | ERC warnings = 0 (no allowlist) | `TestErcSeverityGate::test_erc_warnings_classified` | ✅ |
| 3 | Schematic↔PCB parity = 0 | `TestPcbDrc::test_zero_schematic_parity_issues` | ✅ |
| 4 | Electrical DRC categories = 0 | `TestPcbDrc::test_zero_electrical_drc_violations` | ✅ |
| 5 | No unknown DRC violation types | `TestPcbDrc::test_no_unknown_drc_violation_types` | ✅ |
| 6 | All 12 critical nets verified | `TestCriticalNetMembership` (12 tests) | ✅ |
| 7 | 0 colinear wire overlaps | `TestColinearOverlapLint::test_zero_colinear_overlaps` | ✅ |
| 8 | Net classes correct | `TestNetClassEnforcement` (5 tests) | ✅ |
| 9 | EP footprint locked | `TestEPFootprintInvariants` (8 tests) | ✅ |

Freeze achieved: **2026-02-27**, 97/97 tests passing.

**Scope boundary:** This freeze guarantees schematic correctness, parity,
EP reliability, and net-class integrity. It does **not** guarantee signal
integrity, return path continuity, or analog performance. Those properties
require routed-board DRC, impedance analysis, and measurement.

**Version coupling:** These gates are validated against KiCad 9.0.7.
Changes in KiCad's DRC classification taxonomy or JSON output structure
may require updating the closed-world type sets in
`test_schematic_invariants.py` (§4.2).

---

## 6. Design Rules Learned

### Cardinal rule

> **The generator must never rely on implicit KiCad topology resolution.
> All electrical connections must be expressed as explicit wire segments
> between electrical vertices. No pass-through wires. No overlapping
> segments. No assumptions about how KiCad resolves ambiguous geometry.**

This rule was learned from the REF_ELEC defect (§2). Violating it
produces connectivity failures that are silent at generation time and
only visible through ERC or netlist export. It cost multiple debug
cycles to identify.

### Supporting rules

1. **Never draw a wire that passes through a pin unless it terminates there.**
   KiCad splits pass-through wires at the pin, and the far segment may not
   bind to the intended net.

2. **Never create colinear overlapping wire segments.**
   KiCad's connectivity engine may assign overlapping fragments to different
   nets. This was the root cause of the REF_ELEC defect.

3. **Build nets as explicit segment chains between electrical vertices.**
   Every wire segment should connect exactly two electrical points
   (pin endpoint, junction, label). No redundant overlapping segments.

4. **"Internal self-consistency" ≠ correctness.**
   Tests that only check the generator's internal data structures prove
   nothing about what KiCad will do with the output. All correctness tests
   must parse KiCad tool outputs (ERC JSON, netlist export, DRC JSON, or
   the `.kicad_sch`/`.kicad_pcb` files directly).

5. **Closed-world classification prevents silent rot.**
   When asserting "no electrical DRC violations," you must also assert that
   every observed violation type is in your known set. Otherwise a new KiCad
   violation type gets silently treated as cosmetic.

6. **DRC parity depends on stable project context.**
   `kicad-cli pcb drc --schematic-parity` behavior can vary if the working
   directory or project file association changes. Always run from the project
   directory with explicit paths.

7. **Don't dismiss tool warnings as quirks without proof.**
   The initial REF_ELEC hypothesis ("KiCad misreports this") was wrong.
   If a tool reports a problem and you think it's wrong, prove it with a
   second tool output — don't explain it away.

---

## 7. What's Next

Board is at routing-readiness. All pre-routing gates are green.

**Routing order:**
1. Electrode corridor (CH0–CH31 + REF_ELEC + ELEC_TEST): J5 → U1,
   shortest paths, minimize vias on electrode inputs
2. SPI: J1 → R2–R4 → U1, routed away from electrode region
3. Power: J1 → FB1 → U1 VDD pins, wide traces

**Routing constraints enforced by net classes:**
- ELECTRODE: 0.15mm track, 0.3mm clearance, 0.2mm via drill
- DIGITAL_SPI: 0.2mm track, 0.2mm clearance
- POWER: 0.4mm track, 0.25mm clearance, 0.4mm via drill

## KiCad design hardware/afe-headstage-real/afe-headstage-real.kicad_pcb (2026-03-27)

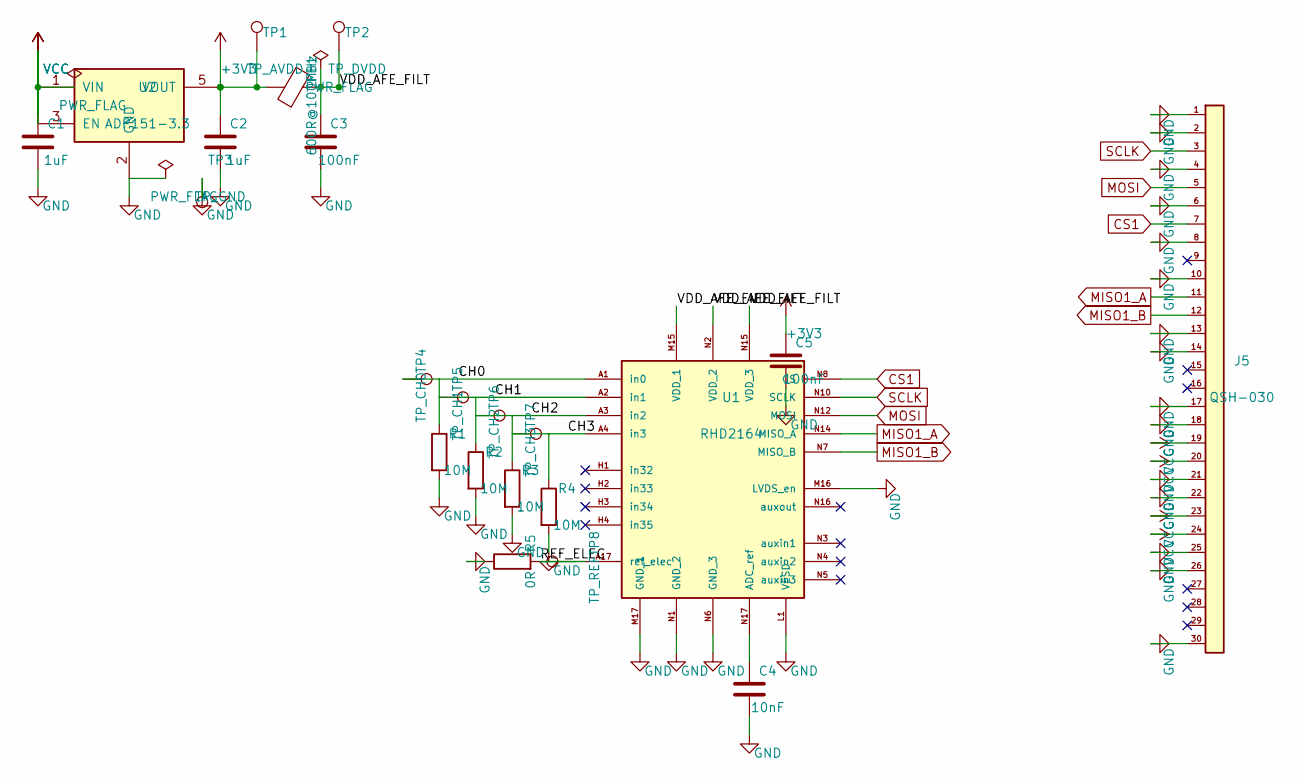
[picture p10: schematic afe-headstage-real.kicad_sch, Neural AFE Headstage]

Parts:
C1, C2: 1uF
C3, C5: 100nF
C4: 10nF
FB1: 600R@100MHz
J5: QSH-030
R1, R2, R3, R4: 10M
R5: 0R
TP1: TP_AVDD
TP2: TP_DVDD
TP3: TP_GND
TP4: TP_CH0
TP5: TP_CH1
TP6: TP_CH2
TP7: TP_CH3
TP8: TP_REF
U1: RHD2164
U2: ADP151-3.3

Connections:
+3V3: C2.1, C5.1, FB1.2, TP1.1, U2.5 (VOUT)
/CH0: R1.1, TP4.1, U1.A1 (in0)
/CH1: R2.1, TP5.1, U1.A2 (in1)
/CH2: R3.1, TP6.1, U1.A3 (in2)
/CH3: R4.1, TP7.1, U1.A4 (in3)
/REF_ELEC: R5.2, TP8.1, U1.A17 (ref_elec)
/VDD_AFE_FILT: C3.1, FB1.1, TP2.1, U1.M15 (VDD_1), U1.N2 (VDD_2), U1.N15 (VDD_3)
CS1: J5.7 (CS1), U1.N8 (CS)
GND: C1.2, C2.2, C3.2, C4.2, C5.2, J5.1 (GND), J5.2 (GND), J5.4 (GND), J5.6 (GND), J5.8 (GND), J5.10 (GND), J5.13 (GND), J5.14 (GND), J5.17 (GND), J5.18 (GND), J5.21 (GND), J5.22 (GND), J5.25 (GND), J5.26 (GND), J5.30 (GND), R1.2, R2.2, R3.2, R4.2, R5.1, TP3.1, U1.L1 (VESD), U1.M16 (LVDS_en), U1.M17 (GND_1), U1.N1 (GND_2), U1.N6 (GND_3), U2.2 (GND)
MISO1_A: J5.11 (MISO1_A), U1.N14 (MISO_A)
MISO1_B: J5.12 (MISO1_B), U1.N7 (MISO_B)
MOSI: J5.5 (MOSI), U1.N12 (MOSI)
unnamed: C4.1, U1.N17 (ADC_ref)
SCLK: J5.3 (SCLK), U1.N10 (SCLK)
VCC: C1.1, J5.19 (VIN), J5.20 (VIN), J5.23 (VIN), J5.24 (VIN), U2.1 (VIN), U2.3 (EN)

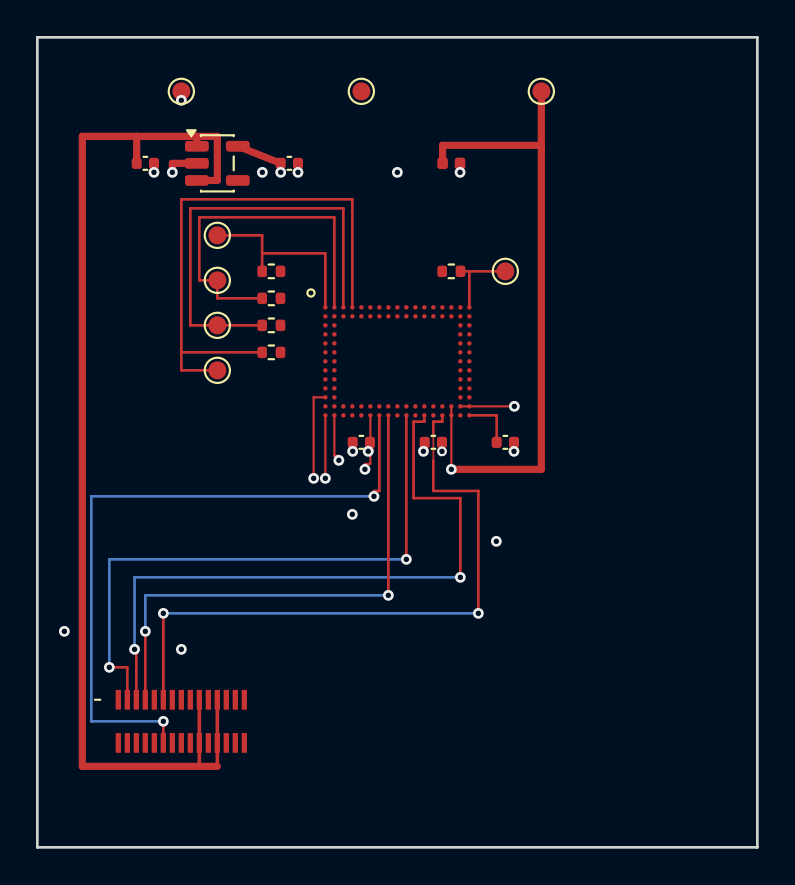
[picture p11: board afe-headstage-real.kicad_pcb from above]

Board: 4 copper layers, 40.0 x 45.0 mm, 22 parts (0 on the bottom side), 15 nets.

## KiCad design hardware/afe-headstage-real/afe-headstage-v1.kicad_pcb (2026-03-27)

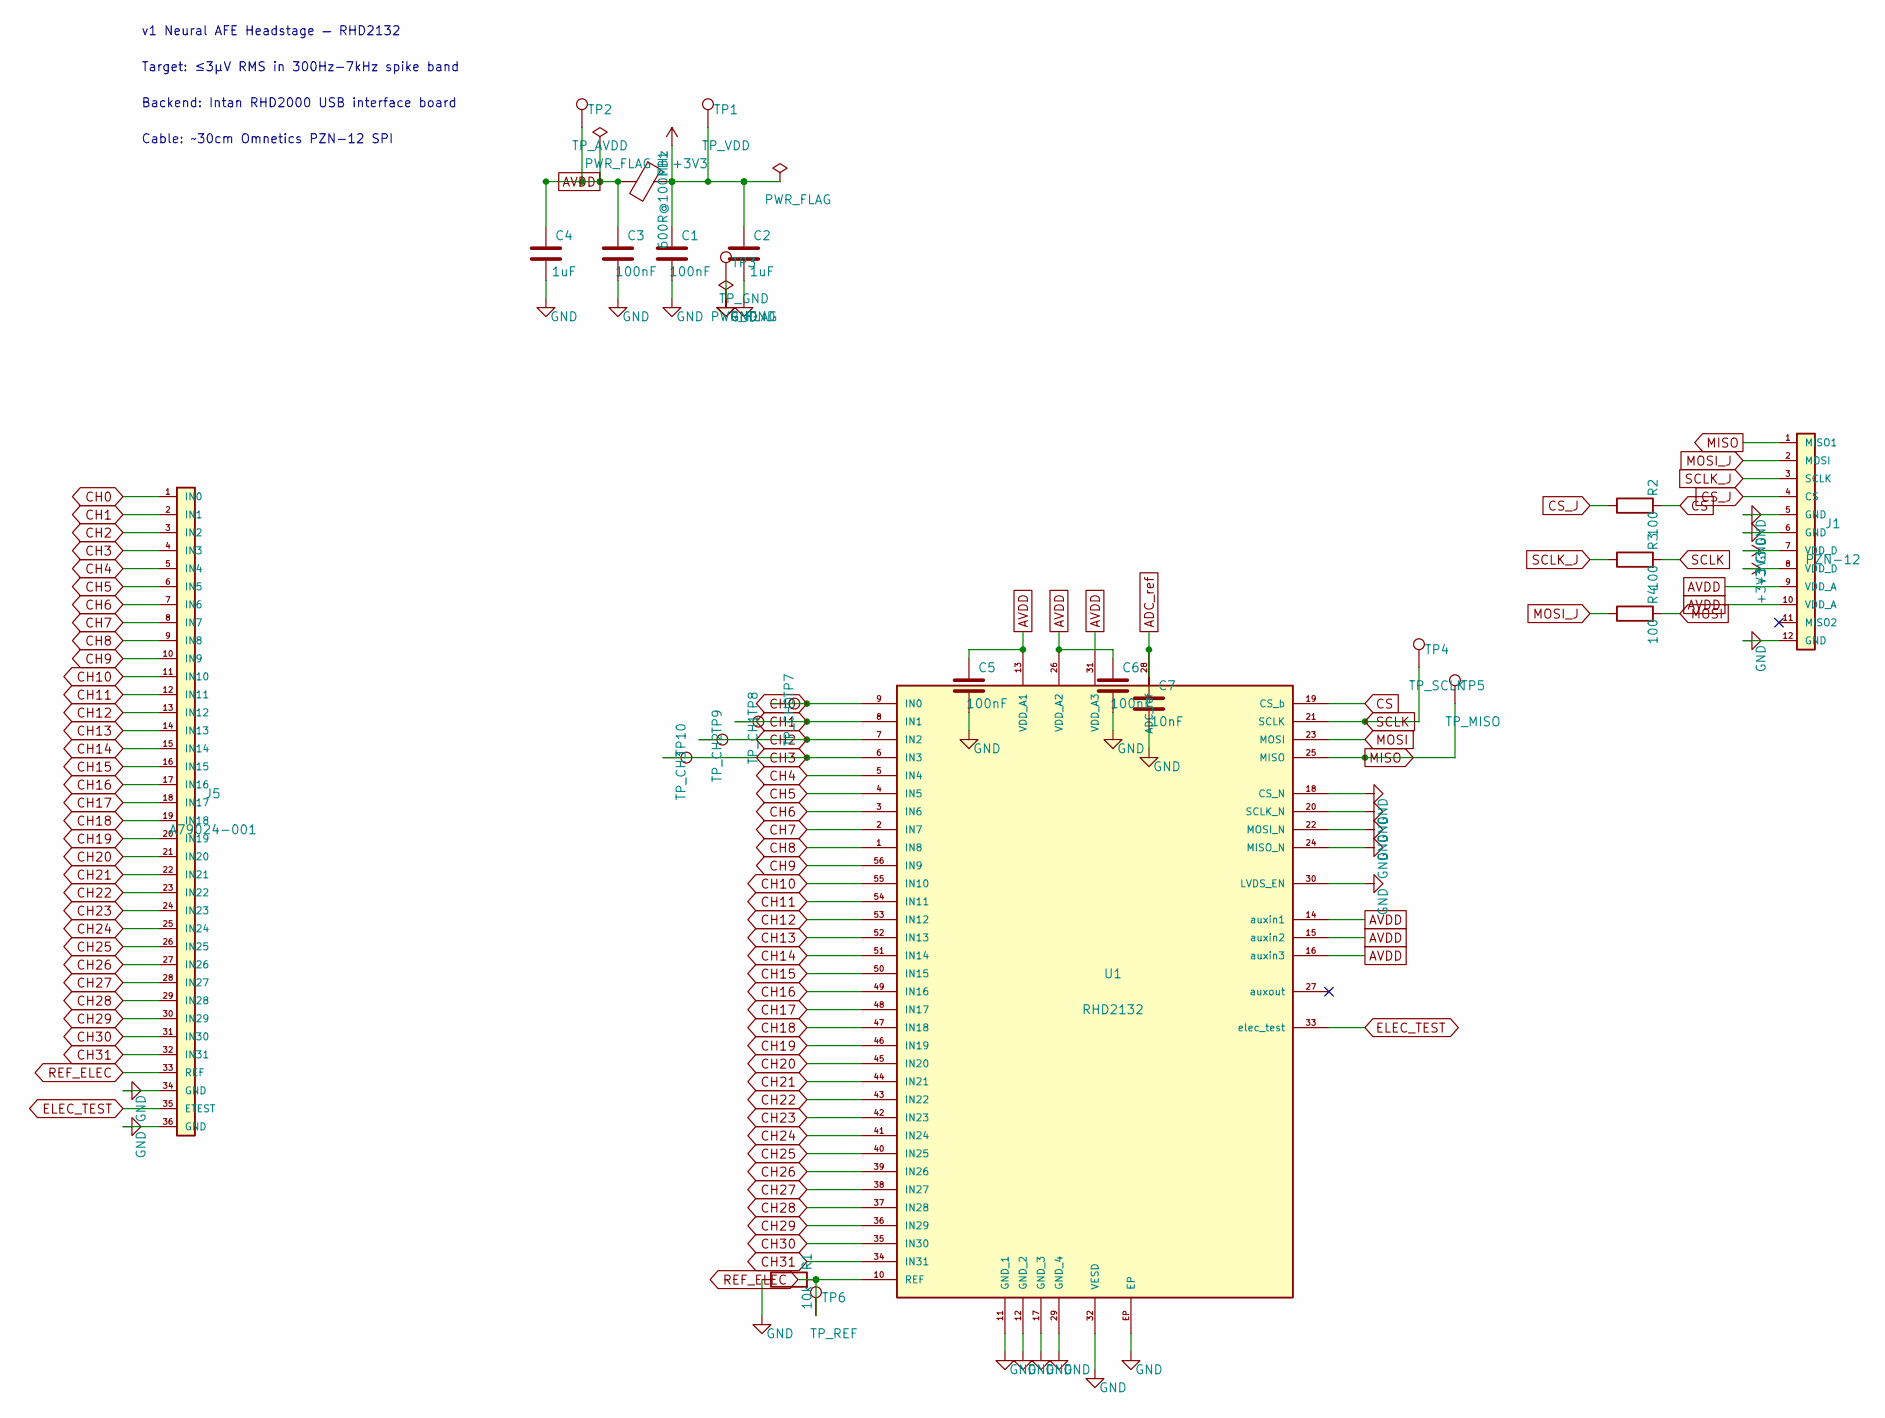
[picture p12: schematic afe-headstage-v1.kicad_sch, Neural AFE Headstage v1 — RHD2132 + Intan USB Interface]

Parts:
C1, C3, C5, C6: 100nF; R_0402_1005Metric
C2, C4: 1uF; R_0402_1005Metric
C7: 10nF; R_0402_1005Metric
FB1: 600R@100MHz; R_0402_1005Metric
J1: PZN-12; Omnetics_PZN-12-AA
J5: A79024-001; Omnetics_A79024_36pin
R1: 10k; R_0402_1005Metric
R2, R3, R4: 100; R_0402_1005Metric
TP1: TP_VDD; TestPoint_Pad_D1.0mm
TP2: TP_AVDD; TestPoint_Pad_D1.0mm
TP3: TP_GND; TestPoint_Pad_D1.0mm
TP4: TP_SCLK; TestPoint_Pad_D1.0mm
TP5: TP_MISO; TestPoint_Pad_D1.0mm
TP6: TP_REF; TestPoint_Pad_D1.0mm
TP7: TP_CH0; TestPoint_Pad_D1.0mm
TP8: TP_CH1; TestPoint_Pad_D1.0mm
TP9: TP_CH2; TestPoint_Pad_D1.0mm
TP10: TP_CH3; TestPoint_Pad_D1.0mm
U1: RHD2132; RHD2132_QFN56

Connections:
+3V3: C1.1, C2.1, FB1.1, J1.7 (VDD_D), J1.8 (VDD_D), TP1.1
ADC_ref: C7.1, U1.28 (ADC_ref)
AVDD: C3.1, C4.1, C5.1, C6.1, FB1.2, J1.9 (VDD_A), J1.10 (VDD_A), TP2.1, U1.13 (VDD_A1), U1.14 (auxin1), U1.15 (auxin2), U1.16 (auxin3), U1.26 (VDD_A2), U1.31 (VDD_A3)
CH0: J5.1 (IN0), TP7.1, U1.9 (IN0)
CH1: J5.2 (IN1), TP8.1, U1.8 (IN1)
CH2: J5.3 (IN2), TP9.1, U1.7 (IN2)
CH3: J5.4 (IN3), TP10.1, U1.6 (IN3)
CH4: J5.5 (IN4), U1.5 (IN4)
CH5: J5.6 (IN5), U1.4 (IN5)
CH6: J5.7 (IN6), U1.3 (IN6)
CH7: J5.8 (IN7), U1.2 (IN7)
CH8: J5.9 (IN8), U1.1 (IN8)
CH9: J5.10 (IN9), U1.56 (IN9)
CH10: J5.11 (IN10), U1.55 (IN10)
CH11: J5.12 (IN11), U1.54 (IN11)
CH12: J5.13 (IN12), U1.53 (IN12)
CH13: J5.14 (IN13), U1.52 (IN13)
CH14: J5.15 (IN14), U1.51 (IN14)
CH15: J5.16 (IN15), U1.50 (IN15)
CH16: J5.17 (IN16), U1.49 (IN16)
CH17: J5.18 (IN17), U1.48 (IN17)
CH18: J5.19 (IN18), U1.47 (IN18)
CH19: J5.20 (IN19), U1.46 (IN19)
CH20: J5.21 (IN20), U1.45 (IN20)
CH21: J5.22 (IN21), U1.44 (IN21)
CH22: J5.23 (IN22), U1.43 (IN22)
CH23: J5.24 (IN23), U1.42 (IN23)
CH24: J5.25 (IN24), U1.41 (IN24)
CH25: J5.26 (IN25), U1.40 (IN25)
CH26: J5.27 (IN26), U1.39 (IN26)
CH27: J5.28 (IN27), U1.38 (IN27)
CH28: J5.29 (IN28), U1.37 (IN28)
CH29: J5.30 (IN29), U1.36 (IN29)
CH30: J5.31 (IN30), U1.35 (IN30)
CH31: J5.32 (IN31), U1.34 (IN31)
CS: R2.2, U1.19 (CS_b)
CS_J: J1.4 (CS), R2.1
ELEC_TEST: J5.35 (ETEST), U1.33 (elec_test)
GND: C1.2, C2.2, C3.2, C4.2, C5.2, C6.2, C7.2, J1.5 (GND), J1.6 (GND), J1.12 (GND), J5.34 (GND), J5.36 (GND), R1.1, TP3.1, U1.11 (GND_1), U1.12 (GND_2), U1.17 (GND_3), U1.18 (CS_N), U1.20 (SCLK_N), U1.22 (MOSI_N), U1.24 (MISO_N), U1.29 (GND_4), U1.30 (LVDS_EN), U1.32 (VESD), U1.EP
MISO: J1.1 (MISO1), TP5.1, U1.25 (MISO)
MOSI: R4.2, U1.23 (MOSI)
MOSI_J: J1.2 (MOSI), R4.1
REF_ELEC: J5.33 (REF), R1.2, TP6.1, U1.10 (REF)
SCLK: R3.2, TP4.1, U1.21 (SCLK)
SCLK_J: J1.3 (SCLK), R3.1

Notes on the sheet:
v1 Neural AFE Headstage — RHD2132
Target: ≤3µV RMS in 300Hz-7kHz spike band
Backend: Intan RHD2000 USB interface board
Cable: ~30cm Omnetics PZN-12 SPI

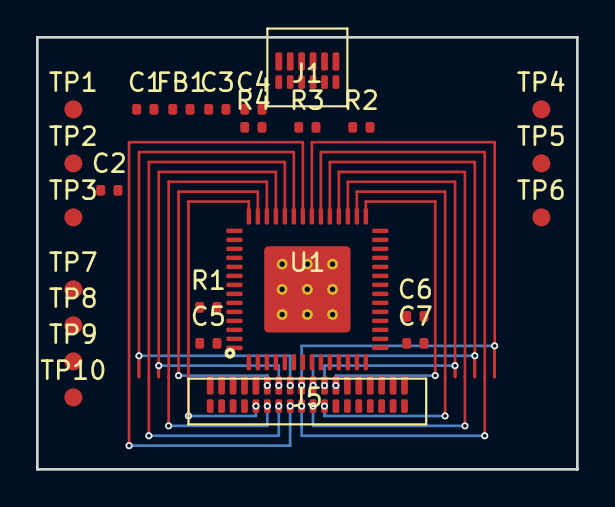
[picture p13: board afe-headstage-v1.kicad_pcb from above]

Board: 4 copper layers, 30.0 x 24.0 mm, 25 parts (0 on the bottom side), 45 nets.

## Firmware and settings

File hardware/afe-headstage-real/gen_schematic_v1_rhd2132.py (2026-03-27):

#!/usr/bin/env python3
"""
gen_schematic_v1_rhd2132.py — v1 Neural AFE Headstage for Intan RHD USB System
================================================================================

Architecture:
  - RHD2132 (32-ch neural AFE, QFN-56, unipolar inputs)
  - Omnetics A79024-001 (36-pin nano-strip) for electrode input (J5)
  - Omnetics PZN-12 (12-pin polarized nano) for SPI cable to Intan USB board (J1)
  - Power from Intan USB interface board via SPI cable (3.3V analog + digital)
  - No on-board LDO — power rail is pre-regulated by Intan interface
  - 16 channels wired for v1, all 32 routed on connector for v2
  - Ferrite bead isolates AVDD from DVDD
  - Test points on power rails, SPI bus, and 4 electrode channels

Target backend: Intan RHD2000 USB interface board (known-good)
Cable: ~30 cm Omnetics PZN-12 SPI cable
Faraday cage: aluminum mesh tabletop around MEA + headstage
Medium: ACSF, room temp → 37°C later

RHD2132 QFN-56 Pin Map (from Intan RHD2000 series datasheet):
  Pins 1-32:  IN[0]-IN[31] — amplifier electrode inputs (unipolar)
  Pin 33:     elec_test — electrode test input
  Pin 34:     REF — reference electrode
  Pin 35:     VDD (analog supply, 3.3V)
  Pin 36:     VDD (analog supply, 3.3V)
  Pin 37:     MISO — SPI master-in slave-out
  Pin 38:     MOSI — SPI master-out slave-in
  Pin 39:     SCLK — SPI clock
  Pin 40:     CS_b — SPI chip select (active low)
  EP (pad 41): GND — exposed thermal/ground pad

  Additional (from datasheet ballmap, functional blocks):
  auxin1, auxin2, auxin3: auxiliary ADC inputs
  auxout: auxiliary DAC output
  ADCref: ADC reference (bypass to GND with 10nF)
  VESD: ESD clamp (tie to GND)
  resA/resB: reserved (leave floating or tie to VDD per datasheet)

Omnetics PZN-12 SPI Cable Pinout (Intan standard):
  Pin 1:  MISO (MISO1)
  Pin 2:  MOSI
  Pin 3:  SCLK
  Pin 4:  CS
  Pin 5:  GND
  Pin 6:  GND
  Pin 7:  VDD_D (+3.3V digital)
  Pin 8:  VDD_D (+3.3V digital)
  Pin 9:  VDD_A (+3.3V analog)
  Pin 10: VDD_A (+3.3V analog)
  Pin 11: MISO2 (optional, unused for single-chip headstage)
  Pin 12: GND

Omnetics A79024-001 (36-pin nano-strip, electrode connector):
  Pins 1-32: electrode channels IN[0]-IN[31]
  Pin 33: REF electrode
  Pin 34: GND (shield/guard)
  Pin 35: elec_test
  Pin 36: GND (shield/guard)
"""

import json
import os
import sys
import uuid

G = 2.54  # mm per grid step


def uid():
    return str(uuid.uuid4())


def g(n):
    """Grid units → mm, rounded to 2 decimal places."""
    return round(n * G, 2)


# ═══════════════════════════════════════════════════════════════════════════
# 1. CANONICAL COORDINATE TRANSFORM — the ONLY place we do Y-inversion
# ═══════════════════════════════════════════════════════════════════════════


def pin_abs(cx, cy, rot, lx, ly):
    """Absolute screen coordinate of a pin connection point.

    This is the ONLY function that converts from symbol-local (Y-up)
    to schematic (Y-down) coordinates.  All routing must use this.
    """
    if rot == 0:
        ax, ay = cx + lx, cy - ly
    elif rot == 90:
        ax, ay = cx - ly, cy - lx
    elif rot == 180:
        ax, ay = cx - lx, cy + ly
    elif rot == 270:
        ax, ay = cx + ly, cy + lx
    else:
        raise ValueError(f"Unsupported rotation: {rot}")
    return round(ax, 2), round(ay, 2)


# ═══════════════════════════════════════════════════════════════════════════
# 2. ENDPOINT UNIQUENESS REGISTRY
# ═══════════════════════════════════════════════════════════════════════════


class WireRegistry:
    """Tracks every wire endpoint → net assignment and detects colinear overlaps."""

    def __init__(self):
        self._coord_to_net = {}
        self._violations = []
        self._segments = []  # (x1, y1, x2, y2) for colinear overlap detection

    def register(self, x, y, net_name):
        key = (round(x, 2), round(y, 2))
        if key in self._coord_to_net:
            existing = self._coord_to_net[key]
            if existing != net_name and existing != "__junction__":
                self._violations.append(
                    f"COLLISION at ({key[0]}, {key[1]}): "
                    f"net '{existing}' already occupies this point, "
                    f"tried to add net '{net_name}'"
                )
                return key
        self._coord_to_net[key] = net_name
        return key

    def register_segment(self, x1, y1, x2, y2):
        """Record a wire segment for colinear overlap checking."""
        self._segments.append((round(x1, 2), round(y1, 2), round(x2, 2), round(y2, 2)))

    def register_junction(self, x, y):
        key = (round(x, 2), round(y, 2))
        return key

    def _check_colinear_overlaps(self):
        """Detect overlapping colinear wire segments.

        Two horizontal segments overlap if they share the same Y and their
        X-ranges intersect (beyond a single shared endpoint).
        Same logic for vertical segments sharing the same X.
        """
        overlaps = []
        n = len(self._segments)
        for i in range(n):
            x1a, y1a, x2a, y2a = self._segments[i]
            for j in range(i + 1, n):
                x1b, y1b, x2b, y2b = self._segments[j]
                # Horizontal: same Y
                if y1a == y2a == y1b == y2b:
                    lo_a, hi_a = min(x1a, x2a), max(x1a, x2a)
                    lo_b, hi_b = min(x1b, x2b), max(x1b, x2b)
                    overlap = min(hi_a, hi_b) - max(lo_a, lo_b)
                    if overlap > 0.01:  # more than a shared endpoint
                        overlaps.append(
                            f"COLINEAR OVERLAP on y={y1a}: "
                            f"[{lo_a}..{hi_a}] ∩ [{lo_b}..{hi_b}] = {overlap:.2f}mm"
                        )
                # Vertical: same X
                elif x1a == x2a == x1b == x2b:
                    lo_a, hi_a = min(y1a, y2a), max(y1a, y2a)
                    lo_b, hi_b = min(y1b, y2b), max(y1b, y2b)
                    overlap = min(hi_a, hi_b) - max(lo_a, lo_b)
                    if overlap > 0.01:
                        overlaps.append(
                            f"COLINEAR OVERLAP on x={x1a}: "
                            f"[{lo_a}..{hi_a}] ∩ [{lo_b}..{hi_b}] = {overlap:.2f}mm"
                        )
        return overlaps

    def check(self):
        overlaps = self._check_colinear_overlaps()
        all_errors = self._violations + overlaps
        if all_errors:
            print("\n╔══ WIRE TOPOLOGY DEFECT DETECTED ══╗", file=sys.stderr)
            for v in all_errors:
                print(f"  ✗ {v}", file=sys.stderr)
            print(
                f"╚══ {len(all_errors)} defect(s) — BUILD FAILED ══╝",
                file=sys.stderr,
            )
            sys.exit(1)

    def summary(self):
        nets = set(self._coord_to_net.values())
        return f"{len(self._coord_to_net)} endpoints, {len(nets)} unique nets"


WREG = WireRegistry()


# ═══════════════════════════════════════════════════════════════════════════
# 3. SYMBOL DEFINITIONS
# ═══════════════════════════════════════════════════════════════════════════

LIB_SYMBOLS = {}


def register_sym(lib_id, text):
    LIB_SYMBOLS[lib_id] = text


# ── Power symbols ─────────────────────────────────────────────────────────

register_sym(
    "power:GND",
    """
    (symbol "power:GND"
      (power)
      (pin_numbers (hide yes))
      (pin_names (offset 0) (hide yes))
      (exclude_from_sim no) (in_bom yes) (on_board yes)
      (property "Reference" "#PWR" (at 0 -6.35 0)
        (effects (font (size 1.27 1.27)) (hide yes)))
      (property "Value" "GND" (at 0 -3.81 0)
        (effects (font (size 1.27 1.27))))
      (property "Footprint" "" (at 0 0 0)
        (effects (font (size 1.27 1.27)) (hide yes)))
      (property "Datasheet" "" (at 0 0 0)
        (effects (font (size 1.27 1.27)) (hide yes)))
      (property "Description" "Power symbol creates a global label with name \\"GND\\" , ground"
        (at 0 0 0) (effects (font (size 1.27 1.27)) (hide yes)))
      (property "ki_keywords" "global power"
        (at 0 0 0) (effects (font (size 1.27 1.27)) (hide yes)))
      (symbol "GND_0_1"
        (polyline (pts (xy 0 0) (xy 0 -1.27) (xy 1.27 -1.27) (xy 0 -2.54) (xy -1.27 -1.27) (xy 0 -1.27))
          (stroke (width 0) (type default)) (fill (type none)))
      )
      (symbol "GND_1_1"
        (pin power_in line (at 0 0 270) (length 0)
          (name "~" (effects (font (size 1.27 1.27))))
          (number "1" (effects (font (size 1.27 1.27)))))
      )
      (embedded_fonts no)
    )""",
)

register_sym(
    "power:+3V3",
    """
    (symbol "power:+3V3"
      (power)
      (pin_numbers (hide yes))
      (pin_names (offset 0) (hide yes))
      (exclude_from_sim no) (in_bom yes) (on_board yes)
      (property "Reference" "#PWR" (at 0 -3.81 0)
        (effects (font (size 1.27 1.27)) (hide yes)))
      (property "Value" "+3V3" (at 0 3.556 0)
        (effects (font (size 1.27 1.27))))
      (property "Footprint" "" (at 0 0 0)
        (effects (font (size 1.27 1.27)) (hide yes)))
      (property "Datasheet" "" (at 0 0 0)
        (effects (font (size 1.27 1.27)) (hide yes)))
      (property "Description" "Power symbol creates a global label with name \\"+3V3\\""
        (at 0 0 0) (effects (font (size 1.27 1.27)) (hide yes)))
      (property "ki_keywords" "global power"
        (at 0 0 0) (effects (font (size 1.27 1.27)) (hide yes)))
      (symbol "+3V3_0_1"
        (polyline (pts (xy -0.762 1.27) (xy 0 2.54))
          (stroke (width 0) (type default)) (fill (type none)))
        (polyline (pts (xy 0 2.54) (xy 0.762 1.27))
          (stroke (width 0) (type default)) (fill (type none)))
        (polyline (pts (xy 0 0) (xy 0 2.54))
          (stroke (width 0) (type default)) (fill (type none)))
      )
      (symbol "+3V3_1_1"
        (pin power_in line (at 0 0 90) (length 0)
          (name "~" (effects (font (size 1.27 1.27))))
          (number "1" (effects (font (size 1.27 1.27)))))
      )
      (embedded_fonts no)
    )""",
)

register_sym(
    "power:PWR_FLAG",
    """
    (symbol "power:PWR_FLAG"
      (power)
      (pin_numbers (hide yes))
      (pin_names (offset 0) (hide yes))
      (exclude_from_sim no) (in_bom yes) (on_board yes)
      (property "Reference" "#FLG" (at 0 1.905 0)
        (effects (font (size 1.27 1.27)) (hide yes)))
      (property "Value" "PWR_FLAG" (at 0 3.81 0)
        (effects (font (size 1.27 1.27))))
      (property "Footprint" "" (at 0 0 0)
        (effects (font (size 1.27 1.27)) (hide yes)))
      (property "Datasheet" "~" (at 0 0 0)
        (effects (font (size 1.27 1.27)) (hide yes)))
      (property "Description" "Special symbol for telling ERC where power comes from"
        (at 0 0 0) (effects (font (size 1.27 1.27)) (hide yes)))
      (property "ki_keywords" "flag power"
        (at 0 0 0) (effects (font (size 1.27 1.27)) (hide yes)))
      (symbol "PWR_FLAG_0_0"
        (pin power_out line (at 0 0 90) (length 0)
          (name "~" (effects (font (size 1.27 1.27))))
          (number "1" (effects (font (size 1.27 1.27)))))
      )
      (symbol "PWR_FLAG_0_1"
        (polyline (pts (xy 0 0) (xy 0 1.27) (xy -1.016 1.905) (xy 0 2.54) (xy 1.016 1.905) (xy 0 1.27))
          (stroke (width 0) (type default)) (fill (type none)))
      )
      (embedded_fonts no)
    )""",
)

# ── Device symbols ────────────────────────────────────────────────────────

register_sym(
    "Device:R",
    """
    (symbol "Device:R"
      (pin_numbers (hide yes))
      (pin_names (offset 0))
      (exclude_from_sim no) (in_bom yes) (on_board yes)
      (property "Reference" "R" (at 2.032 0 90)
        (effects (font (size 1.27 1.27))))
      (property "Value" "R" (at 0 0 90)
        (effects (font (size 1.27 1.27))))
      (property "Footprint" "" (at -1.778 0 90)
        (effects (font (size 1.27 1.27)) (hide yes)))
      (property "Datasheet" "~" (at 0 0 0)
        (effects (font (size 1.27 1.27)) (hide yes)))
      (property "Description" "Resistor"
        (at 0 0 0) (effects (font (size 1.27 1.27)) (hide yes)))
      (property "ki_keywords" "R res resistor"
        (at 0 0 0) (effects (font (size 1.27 1.27)) (hide yes)))
      (property "ki_fp_filters" "R_*"
        (at 0 0 0) (effects (font (size 1.27 1.27)) (hide yes)))
      (symbol "R_0_1"
        (rectangle (start -1.016 -2.54) (end 1.016 2.54)
          (stroke (width 0.254) (type default)) (fill (type none)))
      )
      (symbol "R_1_1"
        (pin passive line (at 0 3.81 270) (length 1.27)
          (name "~" (effects (font (size 1.27 1.27))))
          (number "1" (effects (font (size 1.27 1.27)))))
        (pin passive line (at 0 -3.81 90) (length 1.27)
          (name "~" (effects (font (size 1.27 1.27))))
          (number "2" (effects (font (size 1.27 1.27)))))
      )
      (embedded_fonts no)
    )""",
)

register_sym(
    "Device:C",
    """
    (symbol "Device:C"
      (pin_numbers (hide yes))
      (pin_names (offset 0.254))
      (exclude_from_sim no) (in_bom yes) (on_board yes)
      (property "Reference" "C" (at 0.635 2.54 0)
        (effects (font (size 1.27 1.27)) (justify left)))
      (property "Value" "C" (at 0.635 -2.54 0)
        (effects (font (size 1.27 1.27)) (justify left)))
      (property "Footprint" "" (at 0.9652 -3.81 0)
        (effects (font (size 1.27 1.27)) (hide yes)))
      (property "Datasheet" "~" (at 0 0 0)
        (effects (font (size 1.27 1.27)) (hide yes)))
      (property "Description" "Unpolarized capacitor"
        (at 0 0 0) (effects (font (size 1.27 1.27)) (hide yes)))
      (property "ki_keywords" "cap capacitor"
        (at 0 0 0) (effects (font (size 1.27 1.27)) (hide yes)))
      (property "ki_fp_filters" "C_*"
        (at 0 0 0) (effects (font (size 1.27 1.27)) (hide yes)))
      (symbol "C_0_1"
        (polyline (pts (xy -2.032 0.762) (xy 2.032 0.762))
          (stroke (width 0.508) (type default)) (fill (type none)))
        (polyline (pts (xy -2.032 -0.762) (xy 2.032 -0.762))
          (stroke (width 0.508) (type default)) (fill (type none)))
      )
      (symbol "C_1_1"
        (pin passive line (at 0 3.81 270) (length 2.794)
          (name "~" (effects (font (size 1.27 1.27))))
          (number "1" (effects (font (size 1.27 1.27)))))
        (pin passive line (at 0 -3.81 90) (length 2.794)
          (name "~" (effects (font (size 1.27 1.27))))
          (number "2" (effects (font (size 1.27 1.27)))))
      )
      (embedded_fonts no)
    )""",
)

register_sym(
    "Device:FerriteBead",
    """
    (symbol "Device:FerriteBead"
      (pin_numbers (hide yes))
      (pin_names (offset 0))
      (exclude_from_sim no) (in_bom yes) (on_board yes)
      (property "Reference" "FB" (at -3.81 0.635 90)
        (effects (font (size 1.27 1.27))))
      (property "Value" "FerriteBead" (at 3.81 0 90)
        (effects (font (size 1.27 1.27))))
      (property "Footprint" "" (at -1.778 0 90)
        (effects (font (size 1.27 1.27)) (hide yes)))
      (property "Datasheet" "~" (at 0 0 0)
        (effects (font (size 1.27 1.27)) (hide yes)))
      (property "Description" "Ferrite bead"
        (at 0 0 0) (effects (font (size 1.27 1.27)) (hide yes)))
      (property "ki_keywords" "L ferrite bead inductor filter"
        (at 0 0 0) (effects (font (size 1.27 1.27)) (hide yes)))
      (property "ki_fp_filters" "Inductor_* L_* *Ferrite*"
        (at 0 0 0) (effects (font (size 1.27 1.27)) (hide yes)))
      (symbol "FerriteBead_0_1"
        (polyline (pts (xy -2.7686 0.4064) (xy -1.7018 2.2606) (xy 2.7686 -0.3048) (xy 1.6764 -2.159) (xy -2.7686 0.4064))
          (stroke (width 0) (type default)) (fill (type none)))
        (polyline (pts (xy 0 1.27) (xy 0 1.2954))
          (stroke (width 0) (type default)) (fill (type none)))
        (polyline (pts (xy 0 -1.27) (xy 0 -1.2192))
          (stroke (width 0) (type default)) (fill (type none)))
      )
      (symbol "FerriteBead_1_1"
        (pin passive line (at 0 3.81 270) (length 2.54)
          (name "~" (effects (font (size 1.27 1.27))))
          (number "1" (effects (font (size 1.27 1.27)))))
        (pin passive line (at 0 -3.81 90) (length 2.54)
          (name "~" (effects (font (size 1.27 1.27))))
          (number "2" (effects (font (size 1.27 1.27)))))
      )
      (embedded_fonts no)
    )""",
)

register_sym(
    "Connector:TestPoint",
    """
    (symbol "Connector:TestPoint"
      (pin_numbers (hide yes))
      (pin_names (offset 0.762) (hide yes))
      (exclude_from_sim no) (in_bom yes) (on_board yes)
      (property "Reference" "TP" (at 0 6.858 0)
        (effects (font (size 1.27 1.27))))
      (property "Value" "TestPoint" (at 0 5.08 0)
        (effects (font (size 1.27 1.27))))
      (property "Footprint" "" (at 5.08 0 0)
        (effects (font (size 1.27 1.27)) (hide yes)))
      (property "Datasheet" "~" (at 5.08 0 0)
        (effects (font (size 1.27 1.27)) (hide yes)))
      (property "Description" "test point"
        (at 0 0 0) (effects (font (size 1.27 1.27)) (hide yes)))
      (property "ki_keywords" "test point tp"
        (at 0 0 0) (effects (font (size 1.27 1.27)) (hide yes)))
      (property "ki_fp_filters" "Pin* Test*"
        (at 0 0 0) (effects (font (size 1.27 1.27)) (hide yes)))
      (symbol "TestPoint_0_1"
        (circle (center 0 3.302) (radius 0.762)
          (stroke (width 0) (type default)) (fill (type none)))
      )
      (symbol "TestPoint_1_1"
        (pin passive line (at 0 0 90) (length 2.54)
          (name "1" (effects (font (size 1.27 1.27))))
          (number "1" (effects (font (size 1.27 1.27)))))
      )
      (embedded_fonts no)
    )""",
)


# ═══════════════════════════════════════════════════════════════════════════
# 4. COMPONENT PIN DATABASES
# ═══════════════════════════════════════════════════════════════════════════

PLEN = 5.08  # pin stub length

# ── RHD2132 (QFN-56) ─────────────────────────────────────────────────────
#
# Physical: QFN-56, 8×8mm body, 0.5mm pitch, exposed pad (EP)
# 57 pads total (56 perimeter + 1 EP)
#
# Pin numbering: PHYSICAL QFN-56 pad numbers from Intan Eagle library.
# This ensures schematic pin N == PCB pad N for Update-PCB-from-Schematic.
#
# Authoritative source: Intan RHD2000.lbr, deviceset RHD2132
#   Left side pads 1-14:    IN8..IN0(1-9), REF(10), GND(11-12), VDD1(13), AUXIN1(14)
#   Bottom side pads 15-28: AUXIN2(15), AUXIN3(16), GND(17), CS-(18), CS+(19),
#                           SCLK-(20), SCLK+(21), MOSI-(22), MOSI+(23),
#                           MISO-(24), MISO+(25), VDD2(26), AUXOUT(27), ADC_REF(28)
#   Right side pads 29-42:  GND(29), LVDS_EN(30), VDD3(31), VESD(32),
#                           ELEC_TEST(33), IN31..IN23(34-42)
#   Top side pads 43-56:    IN22..IN9(43-56)
#   EP:                     GND
#
# Schematic visual layout groups functionally, but uses physical pin numbers.

# Enlarged body to fit 33 rows on left side (32 inputs + REF)
RHD_BODY = {"left": -27.94, "right": 27.94, "top": 43.18, "bot": -43.18}

RHD_PINS = []

# ── Left side: IN0-IN31 + REF (using physical pad numbers) ──────────
# Visual order top→bottom: IN0(pad 9), IN1(pad 8), ..., IN31(pad 34), REF(pad 10)
_lx = RHD_BODY["left"] - PLEN
_left_inputs = []
# IN0-IN8 are on physical pads 9,8,7,6,5,4,3,2,1 (reversed on left side)
for ch in range(9):
    _left_inputs.append((f"IN{ch}", str(9 - ch)))  # IN0→pad9, IN1→pad8, ..., IN8→pad1
# IN9-IN22 are on physical pads 56,55,...,43 (top side, reversed)
for ch in range(9, 23):
    _left_inputs.append((f"IN{ch}", str(56 - (ch - 9))))  # IN9→pad56, IN10→pad55, ..., IN22→pad43
# IN23-IN31 are on physical pads 42,41,...,34 (right side, reversed)
for ch in range(23, 32):
    _left_inputs.append((f"IN{ch}", str(42 - (ch - 23))))  # IN23→pad42, IN24→pad41, ..., IN31→pad34

for i, (name, num) in enumerate(_left_inputs):
    _ly = RHD_BODY["top"] - 2.54 - i * 2.54
    RHD_PINS.append((name, num, "passive", _lx, _ly, 0))

# REF below all inputs
_ref_y = RHD_BODY["top"] - 2.54 - 32 * 2.54
RHD_PINS.append(("REF", "10", "passive", _lx, _ref_y, 0))

# ── Right side: SPI, AUX, ELEC_TEST, misc control ───────────────────
_rx = RHD_BODY["right"] + PLEN
_right_pins = [
    # SPI (CMOS mode: only + pins used, - pins tied to GND)
    ("CS_b", "19", "input", 0),        # CS+ (active low)
    ("SCLK", "21", "input", 1),        # SCLK+
    ("MOSI", "23", "input", 2),        # MOSI+
    ("MISO", "25", "output", 3),       # MISO+
    # LVDS negative pins (tied to GND in CMOS mode)
    ("CS_N", "18", "passive", 5),      # CS-
    ("SCLK_N", "20", "passive", 6),    # SCLK-
    ("MOSI_N", "22", "passive", 7),    # MOSI-
    ("MISO_N", "24", "passive", 8),    # MISO-
    # LVDS enable
    ("LVDS_EN", "30", "passive", 10),  # LVDS_EN → GND for CMOS
    # AUX I/O
    ("auxin1", "14", "input", 12),     # tie to VDD per datasheet
    ("auxin2", "15", "input", 13),     # tie to VDD per datasheet
    ("auxin3", "16", "input", 14),     # tie to VDD per datasheet
    ("auxout", "27", "output", 16),    # NC per datasheet
    # Test
    ("elec_test", "33", "passive", 18),
]
for name, num, ptype, idx in _right_pins:
    _ly = RHD_BODY["top"] - 2.54 - idx * 2.54
    RHD_PINS.append((name, num, ptype, _rx, _ly, 180))

# ── Top side: Power pins (VDD×3, ADC_ref) ───────────────────────────
_ty = RHD_BODY["top"] + PLEN
_top_pins = [
    ("VDD_A1", "13", "power_in", -4),    # VDD1 (analog supply)
    ("VDD_A2", "26", "power_in", -2),    # VDD2 (analog supply)
    ("VDD_A3", "31", "power_in", 0),     # VDD3 (analog supply)
    ("ADC_ref", "28", "passive", 3),     # ADC reference (needs 10nF cap)
]
for name, num, ptype, idx in _top_pins:
    RHD_PINS.append((name, num, ptype, idx * 2.54, _ty, 270))
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

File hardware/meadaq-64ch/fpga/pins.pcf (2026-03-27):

# ============================================================================
# MEA DAQ 64-Channel — iCE40UP5K (SG48) Pin Constraints
# Rev 0.1 · 2025-06-28 · LOCKED — matches pin_plan.md
# ============================================================================

# --- SPI bus to RHD2164 (Bank 0) ---
set_io spi_sclk     47   # IOB_2   → RHD2164 SCLK (pin 73)
set_io spi_mosi     46   # IOB_3b  → RHD2164 MOSI (pin 75)
set_io spi_miso     45   # IOB_4a  ← RHD2164 MISO (pin 74)
set_io spi_cs_n     44   # IOB_5b  → RHD2164 CS_N (pin 72)
set_io afe_intan_n  48   # IOB_0a  ← RHD2164 INTAN_N (pin 65)

# --- Synchronous FIFO bus to FT2232H Channel A (Bank 1) ---
set_io ft_data[0]   36   # IOT_36b ↔ FT2232H ADBUS0 (pin 16)
set_io ft_data[1]   37   # IOT_37a ↔ FT2232H ADBUS1 (pin 17)
set_io ft_data[2]   38   # IOT_38b ↔ FT2232H ADBUS2 (pin 18)
set_io ft_data[3]   39   # IOT_39a ↔ FT2232H ADBUS3 (pin 19)
set_io ft_data[4]   40   # IOT_41a ↔ FT2232H ADBUS4 (pin 21)
set_io ft_data[5]   41   # IOT_42b ↔ FT2232H ADBUS5 (pin 22)
set_io ft_data[6]   42   # IOT_43a ↔ FT2232H ADBUS6 (pin 23)
set_io ft_data[7]   43   # IOT_44b ↔ FT2232H ADBUS7 (pin 24)
set_io ft_rxf_n     34   # IOT_46b ← FT2232H ACBUS0 (pin 26) RX not empty
set_io ft_txe_n     32   # IOT_48b ← FT2232H ACBUS1 (pin 27) TX not full
set_io ft_wr_n      31   # IOT_49a → FT2232H ACBUS3 (pin 29) write strobe
set_io ft_rd_n      28   # IOT_50b → FT2232H ACBUS2 (pin 28) read strobe
set_io ft_oe_n      27   # IOT_51a → FT2232H ACBUS6 (pin 33) output enable
set_io ft_clkout    35   # IOT_45a ← FT2232H ACBUS5 (pin 32) 60 MHz clock
set_io ft_siwu_n    33   # IOT_34b → FT2232H ACBUS4 (pin 30) send immediate

# --- UART debug to FT2232H Channel B (Bank 2) ---
set_io uart_tx      12   # IOB_22a → FT2232H BDBUS1/RXD (pin 39)
set_io uart_rx      11   # IOB_23b ← FT2232H BDBUS0/TXD (pin 38)

# --- Status LEDs (Bank 2) ---
set_io led_status   10   # IOB_24a → green LED (heartbeat)
set_io led_error     9   # IOB_25b → red LED (error)

# --- Debug / Misc (Bank 2) ---
set_io dbg_tp1      13   # IOB_20a → test point (frame sync pulse)
set_io osc_48mhz     6   # IOB_16a ← 48 MHz MEMS oscillator → PLL

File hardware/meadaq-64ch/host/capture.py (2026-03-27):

#!/usr/bin/env python3
"""
capture.py — Host capture tool for MEA DAQ stream.

Reads bytes from a serial/USB source (or file), validates frames using
frame_parser.py, and writes validated recordings to .npz files.

Validates:
  - CRC16-CCITT integrity on every frame
  - Monotonic frame_id (gap detection → dropped frames)
  - Monotonic timestamps
  - Status byte health (overflow, SPI errors)
  - Reserved byte/bit compliance

Usage:
  # Live capture from serial port (real hardware):
  python capture.py /dev/tty.usbserial-FT1234 --duration 60 -o recording.npz

  # Offline validation from binary dump:
  python capture.py recording.bin --offline -o validated.npz

  # Dry-run validation (no output, just stats):
  python capture.py recording.bin --offline --stats-only

  # Smoke test with synthetic frames:
  python capture.py --smoke-test
"""

from __future__ import annotations

import argparse
import struct
import sys
import time
from dataclasses import dataclass, field
from pathlib import Path

import numpy as np

# Import from sibling module
sys.path.insert(0, str(Path(__file__).parent))
from frame_parser import (
    FrameParser,
    Frame,
    FRAME_SIZE,
    ADC_CHANNELS,
    AUX_CHANNELS,
    CRC_OFFSET,
    crc16_ccitt,
    MAGIC,
    VERSION,
)


# ── Capture statistics ───────────────────────────────────────────────

@dataclass
class CaptureStats:
    """Accumulated capture session statistics."""
    frames_received: int = 0
    frames_valid: int = 0
    frames_crc_fail: int = 0
    frames_dropped: int = 0
    frames_reserved_dirty: int = 0
    timestamp_violations: int = 0
    overflow_events: int = 0
    spi_errors: int = 0
    start_time: float = 0.0
    end_time: float = 0.0
    first_frame_id: int | None = None
    last_frame_id: int | None = None
    first_timestamp: int | None = None
    last_timestamp: int | None = None
    bytes_received: int = 0

    @property
    def duration_s(self) -> float:
        return self.end_time - self.start_time if self.end_time > self.start_time else 0.0

    @property
    def drop_rate(self) -> float:
        total = self.frames_valid + self.frames_dropped
        return self.frames_dropped / total if total > 0 else 0.0

    @property
    def throughput_bps(self) -> float:
        return self.bytes_received / self.duration_s if self.duration_s > 0 else 0.0

    def summary(self) -> str:
        lines = [
            "═══════════════════════════════════════════════",
            "  Capture Summary",
            "═══════════════════════════════════════════════",
            f"  Duration:           {self.duration_s:.1f} s",
            f"  Bytes received:     {self.bytes_received:,}",
            f"  Throughput:         {self.throughput_bps/1024:.1f} KB/s",
            f"  Frames received:    {self.frames_received}",
            f"  Frames valid:       {self.frames_valid}",
            f"  CRC failures:       {self.frames_crc_fail}",
            f"  Frames dropped:     {self.frames_dropped}",
            f"  Drop rate:          {self.drop_rate:.4%}",
            f"  Reserved dirty:     {self.frames_reserved_dirty}",
            f"  Timestamp viols:    {self.timestamp_violations}",
            f"  Overflow events:    {self.overflow_events}",
            f"  SPI errors:         {self.spi_errors}",
            f"  Frame ID range:     {self.first_frame_id} → {self.last_frame_id}",
            f"  Timestamp range:    {self.first_timestamp} → {self.last_timestamp}",
            "═══════════════════════════════════════════════",
        ]
        return "\n".join(lines)


# ── Device Runtime Contract — Throughput Enforcement ─────────────────
# These values are locked by experiment/device_runtime_contract_v1.md.
# Any capture session that violates these is NOT competition-ready.

RUNTIME_CONTRACT = {
    "expected_fs_hz": 20_000,          # 20 kS/s per channel
    "expected_channels": 14,            # headstage v1 active channels
    "adc_bits": 16,
    "max_drop_rate": 0.001,             # < 0.1%
    "max_crc_fail_rate": 0.0,           # 100% pass required
    "max_timestamp_violations": 0,      # strict monotonicity
    "min_throughput_bps": 448_000,      # 14ch × 20kS/s × 16bit = 4.48 Mbps → floor at 448 kB/s
    "min_duration_s": 10.0,             # too-short captures are unreliable
}


@dataclass
class ContractViolation:
    """One violation of the runtime contract."""
    check: str
    expected: str
    actual: str
    severity: str  # "FAIL" or "WARN"


def validate_against_contract(
    stats: CaptureStats,
    contract: dict | None = None,
) -> list[ContractViolation]:
    """Validate CaptureStats against the device runtime contract.

    Returns list of violations (empty list = PASS).
    """
    c = contract or RUNTIME_CONTRACT
    violations: list[ContractViolation] = []

    # Duration check (WARN, not FAIL — short captures may be intentional)
    if stats.duration_s < c["min_duration_s"]:
        violations.append(ContractViolation(
            check="min_duration_s",
            expected=f"≥ {c['min_duration_s']:.1f} s",
            actual=f"{stats.duration_s:.1f} s",
            severity="WARN",
        ))

    # Drop rate
    if stats.drop_rate > c["max_drop_rate"]:
        violations.append(ContractViolation(
            check="max_drop_rate",
            expected=f"≤ {c['max_drop_rate']:.4%}",
            actual=f"{stats.drop_rate:.4%}",
            severity="FAIL",
        ))

    # CRC integrity
    crc_rate = (stats.frames_crc_fail / stats.frames_received
                if stats.frames_received > 0 else 0.0)
    if crc_rate > c["max_crc_fail_rate"]:
        violations.append(ContractViolation(
            check="max_crc_fail_rate",
            expected="0.0000%",
            actual=f"{crc_rate:.4%}",
            severity="FAIL",
        ))

    # Timestamp monotonicity
    if stats.timestamp_violations > c["max_timestamp_violations"]:
        violations.append(ContractViolation(
            check="max_timestamp_violations",
            expected=f"≤ {c['max_timestamp_violations']}",
            actual=f"{stats.timestamp_violations}",
            severity="FAIL",
        ))

    # Throughput
    if stats.duration_s > 0 and stats.throughput_bps < c["min_throughput_bps"]:
        violations.append(ContractViolation(
            check="min_throughput_bps",
            expected=f"≥ {c['min_throughput_bps']/1024:.1f} KB/s",
            actual=f"{stats.throughput_bps/1024:.1f} KB/s",
            severity="FAIL",
        ))

    return violations
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

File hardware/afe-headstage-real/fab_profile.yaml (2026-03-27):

# Fab Profile — single source of truth for manufacturing capability limits.
#
# This file is read by test_electrical_sanity.py at runtime.
# When you change fabs, update this file — tests auto-adapt.
#
# Do NOT scatter fab constants in Python code.

fab:
  name: "JLC 4-layer Advanced (VIPPO + fine drill)"
  tier: "JLC7628 4-layer 1.6mm stackup — VIPPO option required"
  url: "https://jlcpcb.com/capabilities/pcb-capabilities"
  last_verified: "2026-02-15"

  # VENDOR CAPABILITY GATE — must be confirmed before ordering.
  # This board is NOT orderable as "standard 4-layer."
  # The following advanced capabilities are required:
  #   1. Via-in-pad plated over (VIPPO / IPC-4761 Type VII)
  #   2. 0.20 mm finished PTH drill at 1.6 mm board thickness
  #      (aspect ratio = 8.0:1 — at the mechanical drill limit)
  #   3. ENIG surface finish
  # Vendor must explicitly confirm support for items 1 and 2
  # before order is placed.  Do not assume "standard" pricing
  # or capability covers these requirements.
  vendor_capability_gate:
    vippo_required: true
    min_finished_drill_mm: 0.20
    board_thickness_mm: 1.6
    aspect_ratio: 8.0
    confirmation_required: true

limits:
  min_drill_mm: 0.15                # JLC: 0.15mm mechanical, 0.10mm laser
  min_annular_ring_mm: 0.075        # IPC-6012 Class 2 external; JLC ≥ 0.075
  max_aspect_ratio: 10.0            # JLC: 10:1 mechanical drill
  min_trace_width_mm: 0.10          # JLC: 0.09mm (inner), 0.10mm (outer)
  min_clearance_mm: 0.10            # JLC: 0.09mm; we round up to 0.10
  min_via_via_edge_mm: 0.15         # PCBWay: 0.15mm; JLC: 0.254mm; use tighter
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
